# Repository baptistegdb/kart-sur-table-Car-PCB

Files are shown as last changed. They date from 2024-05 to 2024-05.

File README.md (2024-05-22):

# Projet de carte PCB pour le projet 'Kart Sur Table' 

## Description

Ce dépôt contient les fichiers de conception d'une carte PCB pour le projet 'Kart Sur Table'. La carte a été conçue pour remplacer le montage actuel utilisé cette année, qui est composé de nombreux modules assemblés les uns sur les autres. Le but de cette carte est de centraliser toutes les fonctionnalités nécessaires sur une même carte, afin d'optimiser l'espace disponible et de réduire la taille de l'électronique.
Fichiers

   - Rapport du projet.pdf : rapport de projet détaillant la conception de la carte PCB.
   - Peripherals.SchDoc : schématique des périphériques de la carte (IMU, pont en H pour les moteurs, boutons BOOT et EN, LED de contrôle).
   - power.SchDoc : schématique de l'alimentation de la carte (régulation de la tension en 5V et 3V3).
   - Controller.SchDoc : schématique du microcontrôleur de la carte (ESP32-WROOM-32E).
   - PCB1 25-03-2024 16-33-14.WAS : fichier de sauvegarde automatique de la conception de la carte PCB.
   - PCB1.cctpref : fichier de préférences de la conception de la carte PCB.
   - Schlib1.SchLib : bibliothèque de schémas pour la conception de la carte PCB.
   - PcbLib1.PcbLib : bibliothèque de PCB pour la conception de la carte PCB.
   - PCB1.PcbDoc : fichier de conception de la carte PCB.

## Conception de la carte PCB

La carte PCB a été conçue à l'aide du logiciel Altium Designer. Elle est composée de trois parties principales : les périphériques, l'alimentation et le microcontrôleur.
Périphériques

## Les périphériques de la carte sont les suivants :

   - Une IMU (LSM6DS3TR) pour mesurer l'accélération et la vitesse angulaire du kart.
   - Un pont en H (TB6612FNG) pour contrôler les deux moteurs du kart.
   - Deux boutons (BOOT et EN) pour démarrer et arrêter le microcontrôleur.
   - Deux LED (rouge et verte) pour indiquer l'état du microcontrôleur.

## Alimentation

L'alimentation de la carte est assurée par deux régulateurs de tension :

   - Un régulateur LDO (LMR14050) pour réguler la tension d'entrée (7,4V) à 5V.
   - Un régulateur LDO (TPS7A7002DDAR) pour réguler la tension de 5V à 3V3.

La carte est alimentée par une batterie LiPO de 7,4V/3600mAh, qui est connectée à la carte via un connecteur JST.
Microcontrôleur

Le microcontrôleur de la carte est un ESP32-WROOM-32E. Il est connecté aux périphériques et à l'alimentation de la carte via des connecteurs et des broches d'alimentation.

- pour en savoir plus consultez le Rapport du projet :

[Rapport du projet](https://github.com/baptistegdb/kart-sur-table-Car-PCB/blob/main/Rapport%20du%20projet.pdf)

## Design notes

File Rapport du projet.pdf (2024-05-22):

## Rapport du projet du cours d’électronique /

## carte PCB pour le projet ’Kart Sur Table’

Baptiste Gadebille

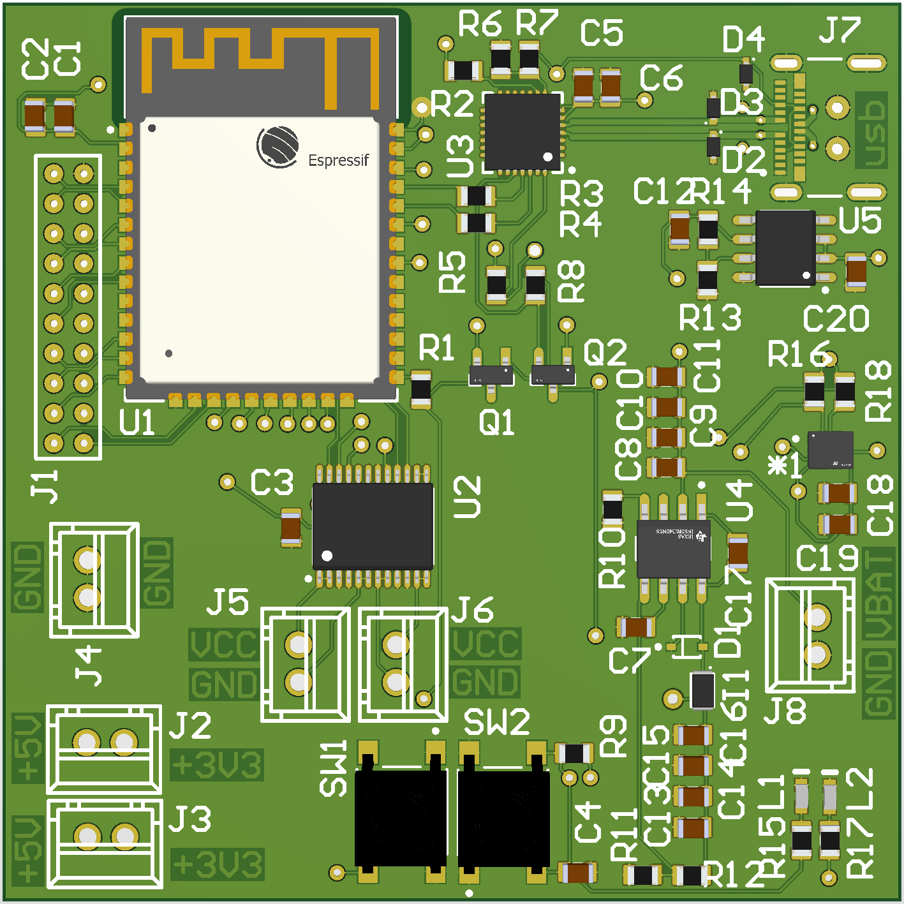
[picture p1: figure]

Figure 1: La Carte

1

Contents

1 Introduction | 5

1.5 Contrôle de trois moteurs à courant continu, avec seulement

2 Les Schématiques | 13
3 Gestion de l’alimentation | 14
4 Périphériques | 21

2

5 Microcontrôleur | 26
6 Composants | 33

3

7 Bilan énergétique | 37
8 Sources | 38

Figure 2: La Carte

4

### 1 Introduction

L’objectif du projet est de créer une carte électronique permettant de piloter à distance une voiture RC. Il est prévu qu’elle puisse fonctionner avec deux moteurs et utiliser une IMU. Son objectif est de devenir la première version d’une voiture RC pour le projet "Kart Sur Table", qui vise à concevoir et à mettre en œuvre un plateau intelligent et polyvalent en combinaison avec des voitures RC. L’objectif de cette carte est de poursuivre le projet de Yday "Kart Sur Table" qui vise à intégrer un plateau écran polyvalent et quatre petits robots capables de se déplacer sur ce plateau. Pour cette version, nous avons créé des petites voitures RC. Cette carte à été réalisé durant le module d’électronique, sur environ dix jours, du choix des composants, du calcule des régulateurs de tensions, à la réalisation de schématiques, en passant par la création de footprint, et jusqu’au routage de la carte.

Le but de cette carte est de remplacer le montage actuel utilisé cette année composé de nombreux modules assemblé les uns sur les autres. Par exemple, actuellement un simple module pont en H l298n prend la place d’un carré de 20mm sur 20mm alors que ce circuit intégré, en lui-même mesure moins d’un cinquième du module.

D’un point de vue unitaire, la taille excessive des modules et l’emplacement des supports semblent insignifiants pour un projet étudiant de petite envergure. Cependant, en prenant une perspective plus globale sur le projet et en considérant notre intention de le prolonger à une deuxième année afin de le terminer et de le rendre à l’état de prototype fonctionnel.

Dans ce but nous voulons faire fabriquer nos propres PCB dans le but d’optimisation les voitures RC, de faire baisser la taille de l’électronique, pour avoir les voitures les plus petites possible, avec le moins de supports internes. Tout cela provoque des contraintes de placement qui pourraient être évitées lors de la modélisation 3D.

5

### 1.1 Solution proposée

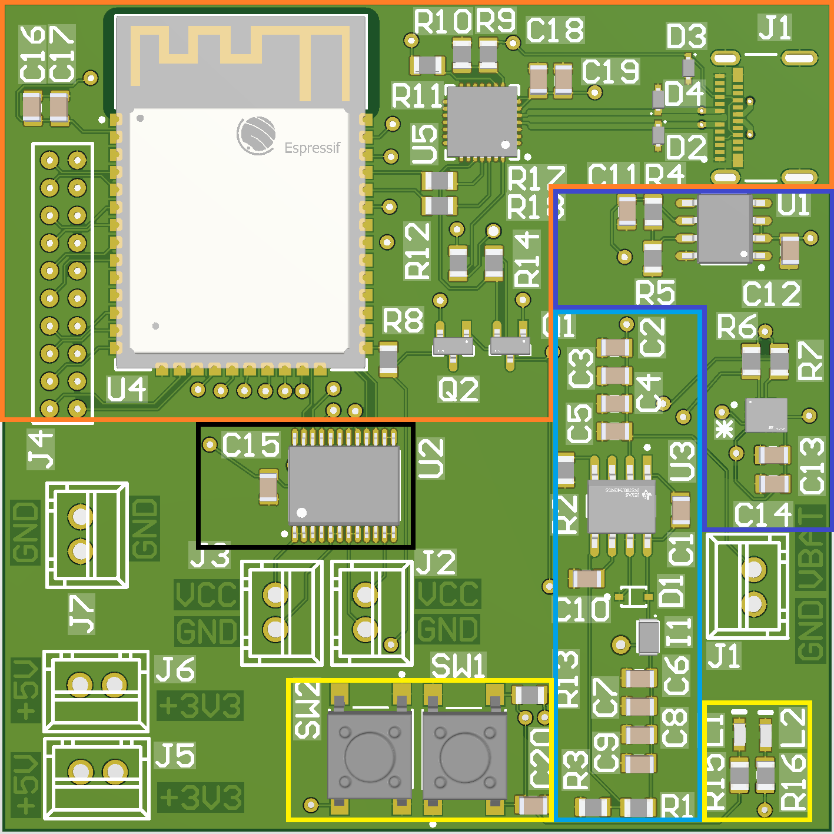
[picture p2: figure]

Figure 3: Une PCB pour remplacer toutes les autres.

La solution proposée est de tout centraliser sur une même carte :

- La carte est un carré de 50 mm par 50 mm
- La zone en orange correspond à la carte l’ESP32-WROOM-32E avec l’USB-C.
- La zone en bleu clair correspond à la partie régulation de la tension en 5v.
- La zone en bleu foncé correspond à la partie régulation de la tension en 3v3, cette zone contient aussi l’IMU juste au-dessus de C13.
- La zone noire correspond au pont en H pour les moteurs, vers les connecteurs J2 et J3.
- La zone jaune correspond aux boutons BOOT et EN ainsi qu’a des LED de contrôle.

6

- Le reste correspond aux connecteurs : J1 pour une batterie 5v, J2 et J3 pour les moteurs, J4 pour les 20 pins programmable de l’ESP, J5 et J6 pour des connecteurs 5v et 3v3 ainsi, de même, le connecteur J7 renvoi aux deux GND.

### 1.2 Dimensionnement des empreintes

Le dimensionnement des empreintes a été réalisé en fonction des spécifications des composants utilisés dans le projet.

Les empreintes des composants CMS sont au format 0805.

Et ont soit été réalisées à l’aide de l’outil IPC Footprint Wizard, soit elles proviennent directement de la bibliothèque Octopart.

### 1.3 Méthodologie du routage

La méthodologie de routage de la carte PCB a été réalisée en suivant les bonnes pratiques de conception. Les composants ont été placés de manière à optimiser l’espace disponible sur la carte bien qu’il y a eu de petites erreurs comme la position de certains condensateurs par exemple. Le routage a été effectué en commençant par les signaux critiques tels que les signaux différentiels, suivis des signaux signaux de données et enfin des d’alimentation. Les pistes ont été routés de manière à éviter les croisements et à minimiser les retours de masse.

Les paires différentielles de l’USB-C :

- Longueur de la piste USB_n : 22.954 mm
- Longueur de la piste USB_p : 23.159 mm

7

- La différence entre les deux longueurs est donc de 0.205mm
- Compte tenu de la tolérance spécifiée de 1 mm pour les paires différentielles USB-C, la différence de 0.205 mm est bien inférieure à cette tolérance. Par conséquent, les longueurs des pistes USB_n et USB_p respectent les spécifications de tolérance pour les paires différentielles USB-C.

– Le calcule de ces Paires différentielles a été fait grâce au logiciel "Saturn Pcb Toolkit" avec une résistance de 90 Ohms

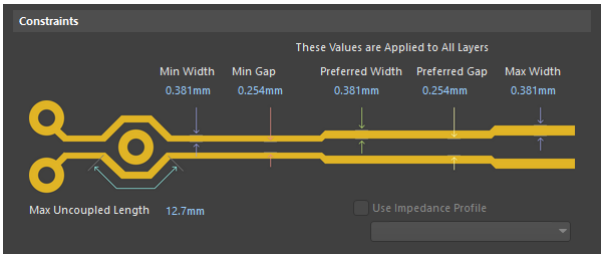
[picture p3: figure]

Figure 4:

8

### 1.4 Contraintes de routage et de fabrication

Lors du routage de la carte PCB, plusieurs contraintes ont été prises en compte pour assurer la fiabilité du circuit. Ces contraintes comprennent :

- Largeur et espacement des pistes : Les pistes ont été dimensionnées en fonction du courant qu’elles doivent supporter et de l’impédance requise. L’espacement entre les pistes a été choisi pour éviter les courtscircuits et les interférences électromagnétiques. Pour garantir une qualité de signal optimale, nous avons suivi les recommandations du fabricant concernant la largeur et l’espacement des pistes.
- Couches de la carte : La carte a été conçue avec quatre couches pour réduire la complexité du routage, améliorer la dissipation thermique et minimiser les interférences électromagnétiques. Ces couches sont les suivantes :

– Top Layer (couches externes)

∗ Signal

– Layer 1 (couche 1)

∗ Ground

– Layer 2 (couche 2)

∗ Power

– Bottom Layer (couches internes)

∗ Ground

La figure suivante illustre la répartition des couches de la carte.

9

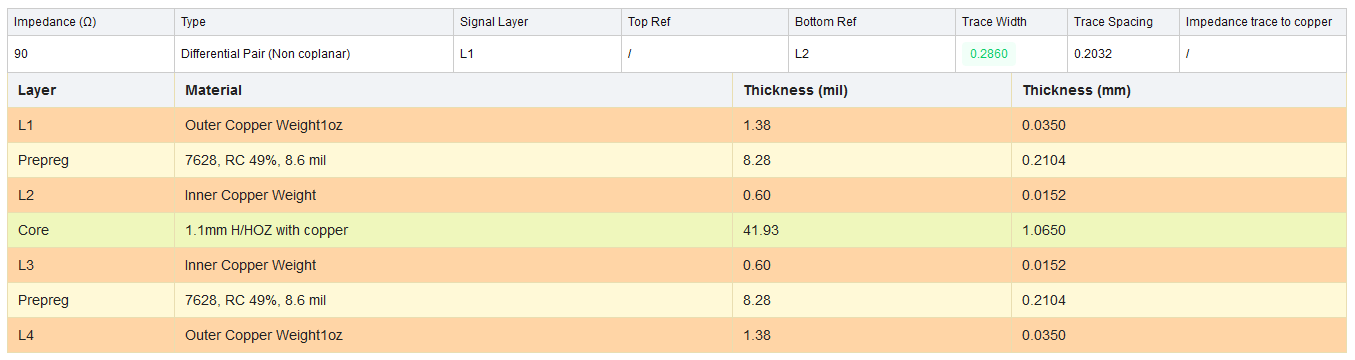
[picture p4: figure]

Figure 5: Tableau des couches de la carte

- Paires différentielles : Les paires différentielles ont été routées avec une différence de longueur de 0.205mm, ce qui est bien inférieure à la tolérance spécifiée de 1mm. Cette précision garantit que les longueurs des pistes USB_n et USB_p respectent les spécifications de tolérance pour les paires différentielles USB-C. Cela permet de minimiser les effets de diaphonie et d’assurer une transmission de signal fiable.
- Contraintes de fabrication : La carte a été conçue en tenant compte des contraintes de fabrication, telles que la taille minimale des vias, la taille des trous de montage et les tolérances de fabrication. Ces contraintes ont été vérifiées à l’aide des outils de contrôle de conception Design Rule Check (DRC). Les règles utilisées proviennent directement des règles de fabrication du site JLCPCB. Cette vérification garantit que la carte peut être fabriquée sans problème et fonctionnera correctement.

10

### 1.5 Contrôle de trois moteurs à courant continu, avec

seulement deux connectés à un pont en H

Le projet prévoit le contrôle de trois moteurs à courant continu, dont deux seront connectés à un pont en H pour permettre un contrôle bidirectionnel de la vitesse et de la direction. Le troisième moteur aura un contrôle unidirectionnel qui doit servir de bumper. Le moteur choisi est un mini moteur à engrenages 6V 50tr/min (12FN20).

### 1.6 Utilisation d’un micro-contrôleur de type ESP32

Le projet utilisera un micro-contrôleur ESP32 pour le traitement des données et le contrôle des composants. Ce micro-contrôleur a été choisi pour sa polyvalente, sa puissance de traitement qui correspond a nos besoins ainsi que sa connectivitée sans fil.

### 1.7 Commande des moteurs

La commande des moteurs sera assurée par le micro-contrôleur ESP32. Deux des moteurs seront connectés à un pont en H pour permettre un contrôle bidirectionnel de la vitesse et de la direction. Le troisième moteur aura un contrôle unidirectionnel, ce qui signifie qu’il ne pourra tourner que dans un sens.

### 1.8 Connectivité

Le projet utilisera une IMU (Unité de Mesure Inertielle) qui communique en I2C ou en SPI. Pour ce projet l’I2C à été choisi pour communique entre l’esp32 et l’IMU. L’IMU fournira des données sur l’orientation, la vitesse et

11 l’accélération de la voiture RC.

### 1.9 Contraintes supplémentaires

La conception de la carte doit tenir compte de la compacité et de la robustesse pour s’adapter à l’environnement de la voiture RC. Les composants doivent être sélectionnés pour leur faible consommation d’énergie afin de prolonger la durée de vie de la batterie. De plus, le système doit être conçu avec une certaine tolérance aux vibrations et aux chocs pour assurer un fonctionnement correct dans diverses conditions d’utilisation. Cela implique le choix de composants résistants et une conception mécanique adéquate.

12

### 2 Les Schématiques

La carte électronique en question se compose de trois parties principales de la carte électronique : Chaque partie est détaillée avec son fonctionnement et les composants utilisés.

la partie puissance, les périphériques et le micro-contrôleur.

La gestion de l’alimentation est un élément crucial dans tout système électronique, et cette section décrit comment la batterie LiPO de 7,4V/3600mAh est utilisée pour alimenter la carte électronique.

La section suivante décrit les périphériques tels que l’IMU, le pont en H et les connecteurs. Enfin, la section du micro-contrôleur décrit l’utilisation de l’ESP32-WROOM32E dans le projet de voiture RC.

Les choix des composants ont été guidés par plusieurs facteurs tels que la performance, la fiabilité, la consommation d’énergie et la compatibilité avec les autres composants du système.

Le choix des composants pour cette carte électronique a été guidé par plusieurs facteurs, notamment la performance, la fiabilité, la consommation d’énergie et la compatibilité avec les autres composants du système.

13

### 3 Gestion de l’alimentation

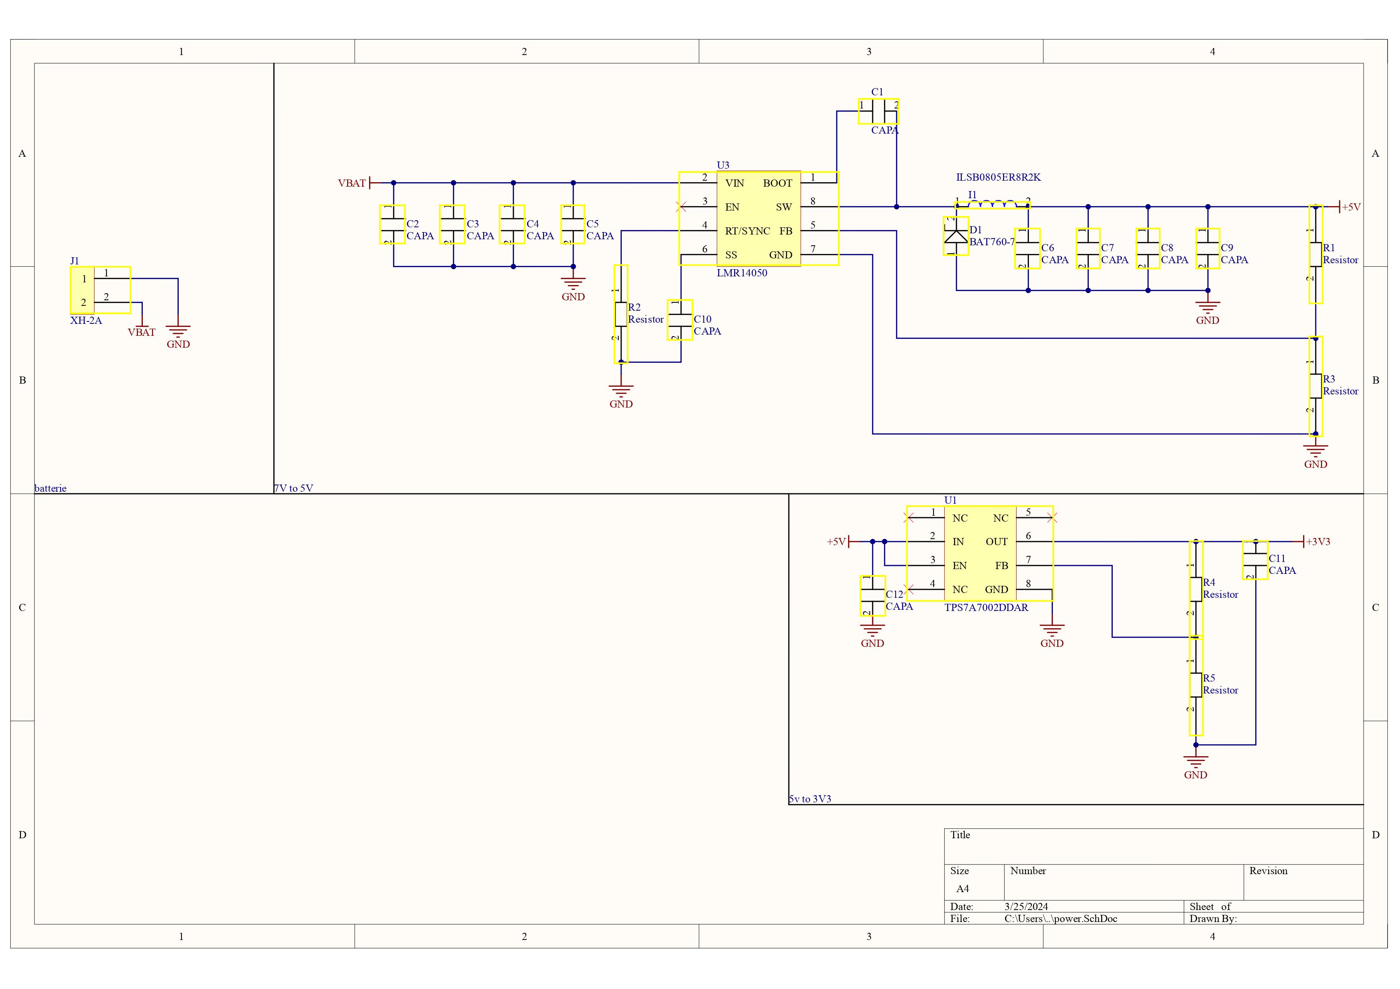
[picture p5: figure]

Figure 6: Enter Caption

La gestion de l’alimentation est un élément crucial dans tout système électronique. Elle permet de fournir l’énergie nécessaire au fonctionnement de tous les composants. Dans notre projet de voiture RC, nous avons utilisé une batterie LiPO de 7,4V/3600mAh pour alimenter la carte électronique qui convertie la tension vers 5v, et enfin à du 3v3 vers le micro-contrôleur .

La section de gestion de l’alimentation de la carte électronique se compose d’un connecteur pour la batterie, d’un régulateur de tension LDO LMR14050 pour fournir une tension de 5V, et d’un régulateur de tension LDO TPS7A7002DDAR pour fournir une tension de 3,3V.

Le connecteur pour la batterie doit être compatible avec la batterie spécifique

14 utilisée dans le projet. Dans ce cas, le connecteur doit correspondre aux spécifications de la batterie LiPO 7,4V/3600mAh 60C. La batterie choisie pour ce projet a une capacité de 3600 mAh et une tension nominale de 7,4
V. Cela signifie qu’elle peut fournir une quantité d’énergie maximale de 26,64 Wh (watt-heures). La capacité élevée de cette batterie permet une durée de fonctionnement prolongée de la voiture RC.

15

### 3.0.1 LDO LMR14050

Le montage proposé pour le régulateur à découpage LMR14050 a été vérifié et validé en se basant sur les calculs et recommandations fournis dans la datasheet du composant.

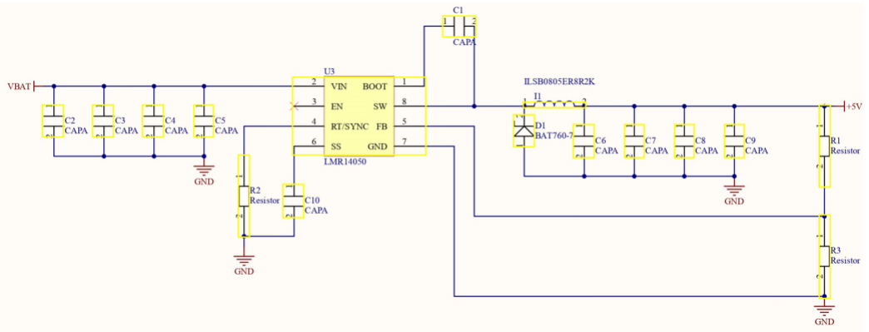
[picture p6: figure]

Figure 7: ldo 7v to 5v

- Condensateurs d’entrée : Quatre condensateurs ont été placés entre l’entrée VIN et la masse, avec des valeurs respectives de 47 µF, 22 µF, 22 µF et 100 µF. Cette combinaison de condensateurs assure un découplage efficace de l’alimentation d’entrée et réduit les ondulations.
- Résistance RT/SYNC : Une résistance de 84,5 k Ohms a été placée sur le pin RT/SYNC et reliée à la masse. Cette résistance détermine la fréquence de découpage du régulateur. Selon la datasheet, la fréquence de découpage (fSW) peut être calculée à l’aide de l’équation suivante :
- Selon la datasheet, la fréquence de découpage (fSW) peut être calculée à l’aide de l’équation suivante :

fSW = 1/(2.4 ∗ RT)

Avec RT = 84,5 k Ohms, la fréquence de découpage est :

fSW = 1/(2.4 ∗ 84.5kOhms) = 300kHz

16

Cette valeur correspond à la fréquence de découpage souhaitée pour le montage.

- Condensateur de soft-start : Un condensateur de 20 nF a été placé sur la pin SS et relié à la masse. Ce condensateur est utilisé pour contrôler le temps de démarrage progressif du régulateur.
- Selon la datasheet, le temps de démarrage progressif (tSS) peut être calculé à l’aide de l’équation suivante :

tSS = CSS ∗ (V IN/ISS)

où CSS est la valeur du condensateur de soft-start, VIN est la tension d’entrée, et ISS est le courant de charge du condensateur de soft-start (3 µA). Avec CSS = 20 nF, VIN = 7,4 V, et ISS = 3 µA, le temps de démarrage progressif est :

tSS = 20nF ∗ (7, 4V/3A) = 5ms

Cette valeur correspond au temps de démarrage progressif souhaité pour le montage.

- Condensateur de bootstrap : Un condensateur de 100 nF a été placé entre le pin BOOT et le pin SW. Ce condensateur est utilisé pour fournir une tension de polarisation au circuit de commande du MOSFET interne. La datasheet recommande d’utiliser un condensateur de 100 nF pour cette application.
- Diode, inductance et condensateurs de sortie : Une diode, une bobine de 8,2 µH et quatre condensateurs de 47 µF ont été placés entre le pin SW et le rail de sortie de 5 V. Ces composants forment le circuit de sortie du régulateur. La datasheet recommandé d’utiliser une inductance comprise entre 4,7 µH et 22 µH pour une application de 5 V/5 A.

17

Le choix d’une inductance de 8,2 µH est légèrement supérieur à cette recommandation, mais reste adapté au montage. Les condensateurs de sortie assurent une bonne découplage de la tension de sortie et réduisent les ondulations.

- Pont diviseur de tension : Un pont diviseur de tension a été mis en place entre le rail de sortie de 5 V et le pin FB, composé des résistances R1 de 100 k Ohms et R3 de 17,8 k Ohms. Ce pont diviseur de tension est utilisé pour réguler la tension de sortie du régulateur. Selon la datasheet,
- Selon la datasheet, la tension de sortie (VOUT) peut être calculée à l’aide de l’équation suivante :

V OUT = V F B ∗ (1 + R1/R3)

où VFB est la tension de référence interne du régulateur (0,75 V). Avec R1 = 100 k Ohms et R3 = 17,8 k Ohms, la tension de sortie est :

V OUT = 0, 75V ∗ (1 + 100kOhms/17, 8kOhms) = 5V

18

### 3.0.2 LDO TPS7A7002DDAR

- Le régulateur LDO TPS7A7002 est utilisé dans le montage pour réguler la tension d’entrée de 5V à une tension de sortie de 3,3V. Pour ce faire, un pont diviseur de tension est utilisé pour fournir une tension de référence à la broche FB du régulateur.

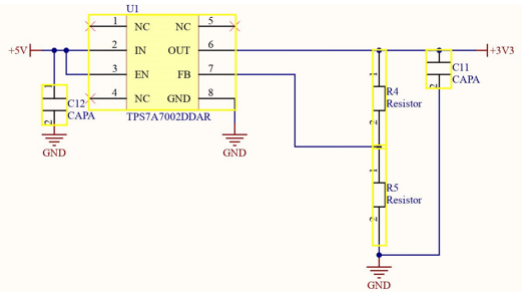
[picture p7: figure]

Figure 8: LDO 5v to 3v3

- La valeur de la tension de référence est déterminée par les résistances R1 et R2 du pont diviseur de tension.
- La formule pour calculer la tension de sortie (Vout) du régulateur est la suivante :

V out = V ref ∗ (1 + R1/R2)

- Où Vref est la tension de référence (dans ce cas, la tension à la broche FB) et R1 et R2 sont les résistances du pont diviseur de tension.

19

- Dans le montage, R1 = 169 k Ohms et R2 = 30,1 k Ohms. En utilisant ces valeurs et en sachant que la tension de sortie souhaitée est de 3,3 V, nous pouvons résoudre l’équation pour trouver la tension de référence nécessaire à la broche FB :

3, 3V = V ref ∗ (1 + 169kOhms/30, 1kOhms)

V ref = 3, 3V/(1 + 169kOhms/30, 1kOhms) = 0, 5V

- Par conséquent, la tension de référence à la broche FB doit être de 0,5 V pour obtenir une tension de sortie de 3,3 V.
- Le condensateur de 100 nF entre la broche IN et la broche EN est utilisé pour réduire le bruit et améliorer la stabilité du régulateur. Le condensateur de 100 nF entre le nœud du pont diviseur de tension et la sortie de 3,3 V est également utilisé pour réduire le bruit et améliorer la stabilité du régulateur.

20

### 4 Périphériques

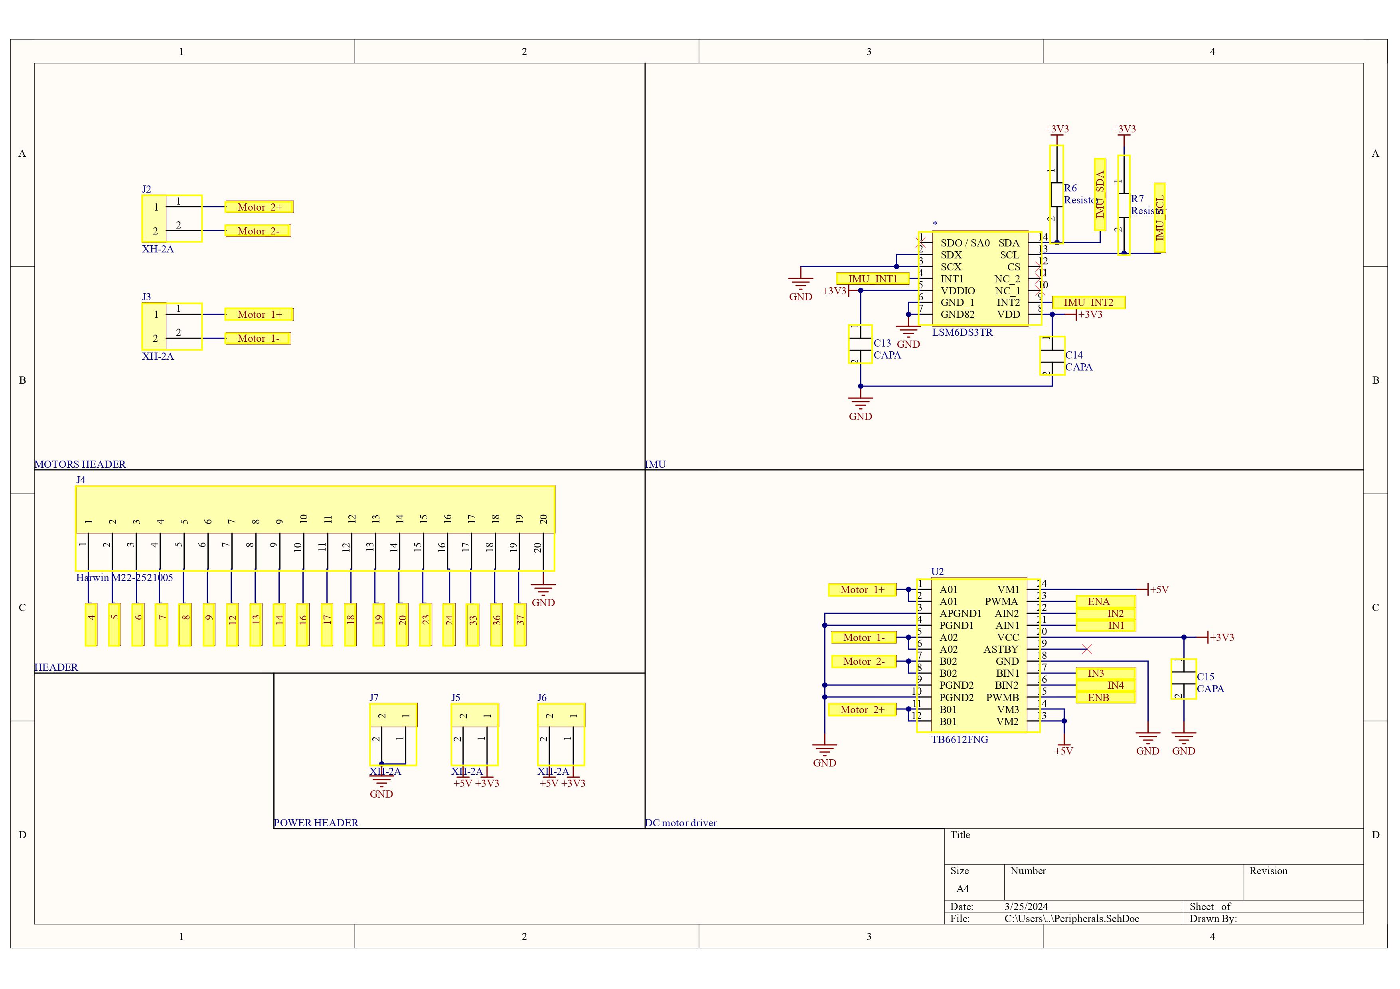
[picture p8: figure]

Figure 9: Les Périphériques

La carte électronique est équipée de plusieurs périphériques clés, notamment une unité de mesure inertielle (IMU), un pont en H, des connecteurs pour les moteurs et des connecteurs d’alimentation. L’IMU est utilisée pour mesurer l’accélération, la vitesse angulaire et l’orientation du robot, tandis que le pont en H est utilisé pour contrôler les moteurs du robot. Les connecteurs d’alimentation fournissent l’énergie nécessaire au fonctionnement de la carte électronique et des périphériques associés.

21

### 4.1 Le Pont en H

Le pont en H est utilisé pour contrôler les moteurs. Dans ce cas, le condensateur C15 est utilisé comme filtre low pass. Le TB6612FNG fourni un courant

de sortie importante et offre une faible résistance à l’état ON, ce qui améliore l’efficacité énergétique. De plus, il offre, des protections intégrées, et à un boîtier compact, parfait pour des contraintes de places. Ces caractéristiques

en font un pont en H équilibré et performant. De plus il permet de piloter deux moteurs indépendamment l’un de l’autre. Avec un courant de sortie maximum de 3,2 A pour les deux sorties, et une protection thermique.

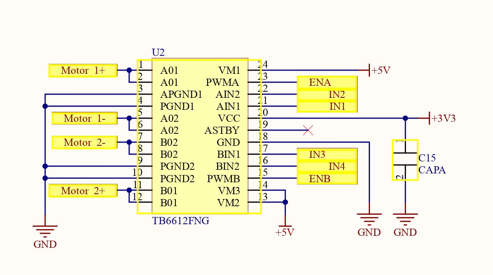
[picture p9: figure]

Figure 10: Le pont en H

22

### 4.2 l’IMU (LSM6DS3TR)

Le design utilisé pour l’IMU LSM6DS3TR reprend celui de la documentation technique du composant. Dans ce cas d’utilisation, les condensateurs C13 et C14 servent de filtres low pass, tandis que les résistances R6 et R7 servent de filtres high pass.

Ce circuit imprimé intègre un accéléromètre 3 axes, un gyroscope 3 axes et un magnétomètre 3 axes, le LSM6DS3TR servira a terme pour une implementation de l’odométrie.

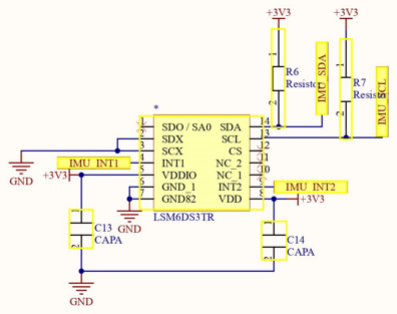
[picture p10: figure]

Figure 11: L’IMU

23

### 4.3 Les connecteurs

Le connecteur XH-2A est un choix pratique et efficace pour les applications nécessitant une connexion fil à carte.

Ce connecteur à insertion est facile d’utilisation, de plus, ce connecteur est durable.

Avec un pas de 2,5 mm, le connecteur XH-2A est relativement petit, ce qui le rend idéal pour les applications où l’espace est limité.

Les headers XH-2A sont utilisés pour alimenter des modules externes comme les moteus DC, ou autres, via les broches GND, 3V3, 5V.

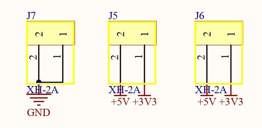
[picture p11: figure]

Figure 12: Connecteurs +5V, +3V3, GND

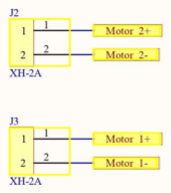
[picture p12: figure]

Figure 13: Deux connecteurs pour les moteurs

Les connecteurs moteurs relient directement les moteurs au pont en H.

24

L’autre connecteur est utilisés pour pouvoir ajouter si besoin des capteurs et des actionneurs. Ils permettent également d’améliorer le système.

Ce connecteur aux nombreux pins est en deux fois dix broches, cela permet de concentrer les broches au même endroit plutôt que de n’avoir pas plusieurs connecteurs routés au microcontrôleur.

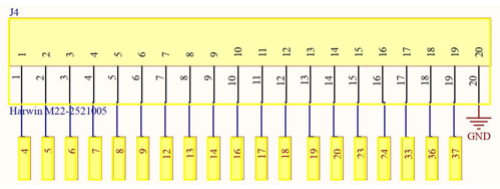
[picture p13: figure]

Figure 14: Connecteurs esp32

25

### 5 Microcontrôleur

Le microcontrôleur utilisé dans cette carte électronique est l’ESP32-WROOM32E.

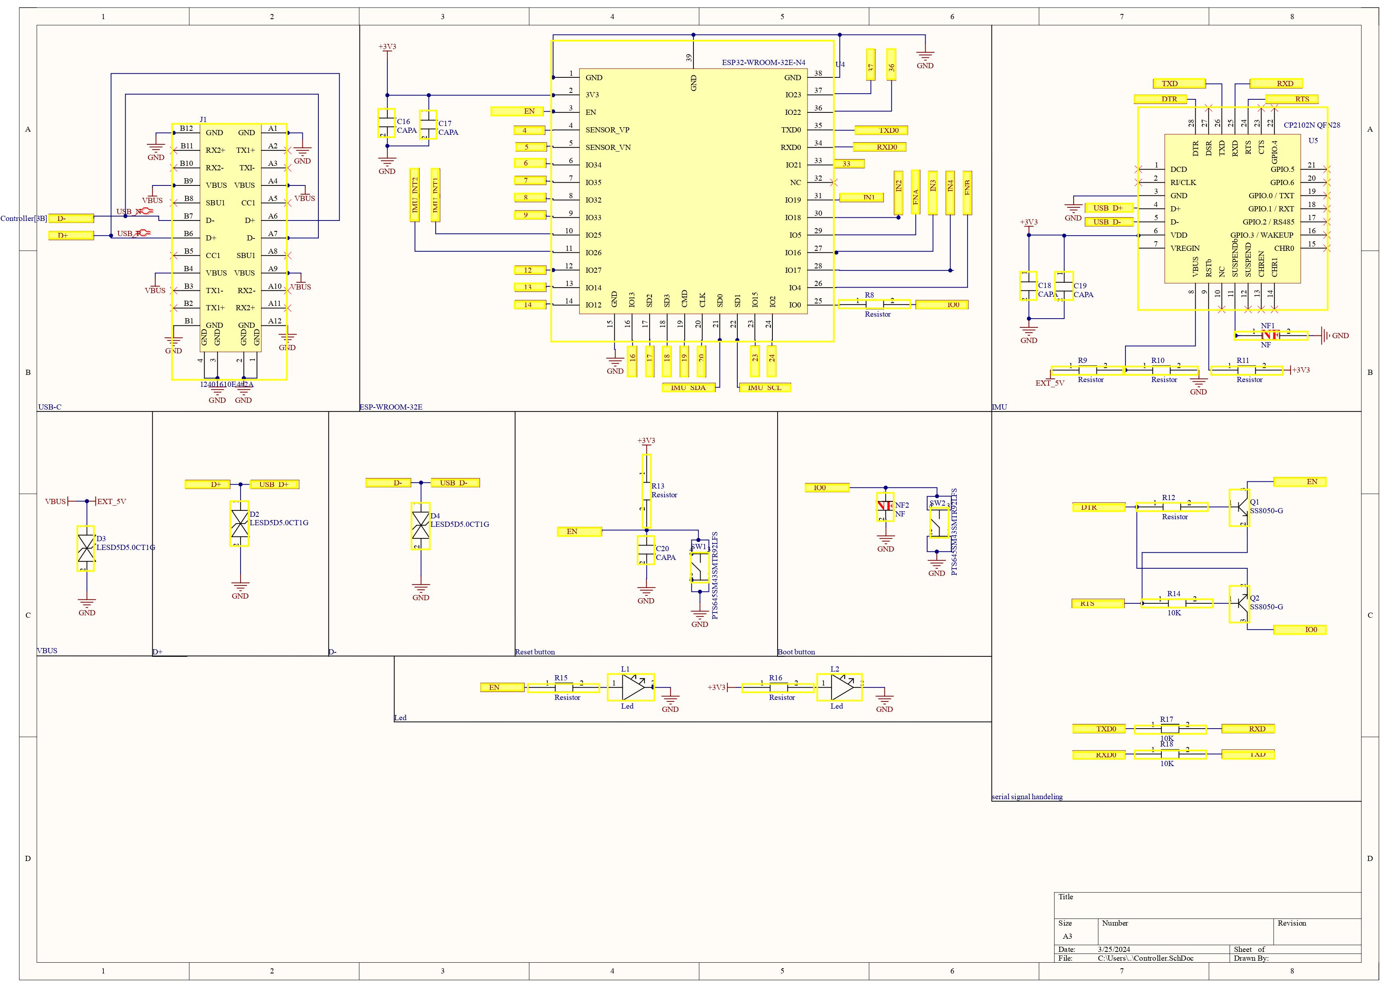
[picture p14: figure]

Figure 15: Enter Caption

L’ESP32-WROOM32E est un microcontrôleur populaire utilisé dans de nombreuses applications IoT. Dans notre projet de voiture RC, nous avons connecté les différentes broches de l’ESP32 aux headers correspondants sur la carte électronique.

Le microcontrôleur a une faible consommation d’énergie, ce qui permet une durée de fonctionnement prolongée de la voiture RC lorsque le microcontrôleur n’est pas en fonctionnement actif.

26

Nous avons également utilisé des boutons Reset et Boot pour réinitialiser le microcontrôleur et passer en mode de téléchargement de programme, ainsi qu’un pont USB pour convertir les signaux USB en signaux série et connecter la carte électronique à un ordinateur ou à un autre périphérique USB.

Le connecteur USB est utilisé pour charger le programme dans le microcontrôleur et communiquer avec la carte électronique.

La carte possède des LED de vérifications, ces leds sont utilisées pour vérifier si le ’3v3’ et le ’EN’ fonctionnent correctement. Elles servent de vérification pour s’assurer que la carte électronique est correctement alimentée.

Figure 16: Led de vérifications

27

### 5.1 ESP32-WROOM32E

L’ESP32-WROOM32E est un microcontrôleur populaire utilisé dans de nombreuses applications IoT, le modèle L’ESP32-WROOM32E à l’avantage d’avoir une antenne intégré.

Dans ce cas, les condensateurs C16 et C17 servent de filtres low pass. Les différents pins présents sur l’esp sont connecté aux headers.

Le microcontrôleur ESP32-WROOM-32E a une consommation d’énergie de 180 mA en mode actif et de 10 µA en mode veille profonde.

Cette faible consommation d’énergie en mode veille profonde permet une durée de fonctionnement prolongée de la voiture RC lorsque le microcontrôleur n’est pas en fonctionnement actif.

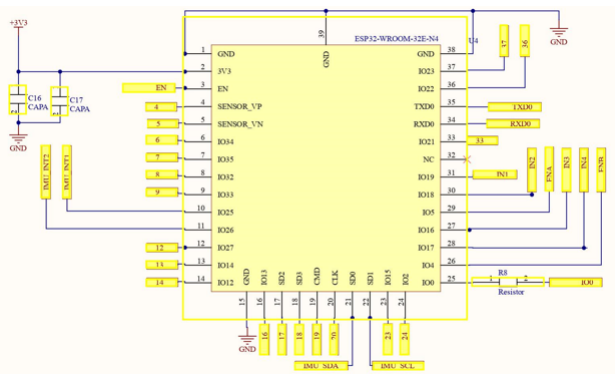
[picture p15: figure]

Figure 17: ESP-WROOM-32E

28

### 5.2 Broches ENABLE/IO0 et boutons Reset et Boot

Les boutons Reset et Boot sont utilisés pour réinitialiser le microcontrôleur et pour passer en mode de téléchargement de programme. Pour le bouton reset, un nœud composé du bouton poussoire et d’un filtre low pass, ainsi que d’un filtre high pass est utilisé en amont de la pin EN.

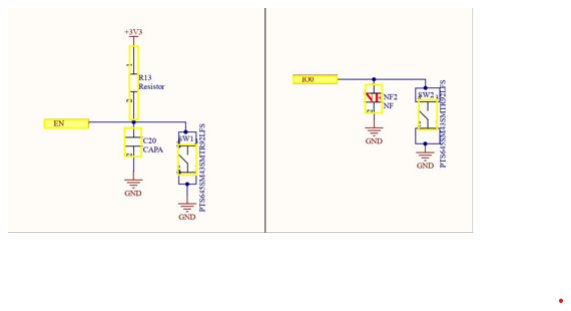
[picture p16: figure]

Figure 18: Boutons Reset et Boot

La séquence automatique des broches ENABLE/IO0 est utilisée pour le téléchargement du programme sur l’ESP32-WROOM32E. Le design de cette partie provient du pont USB. Les transistors utilisés dans ce schéma sont de type NPN.

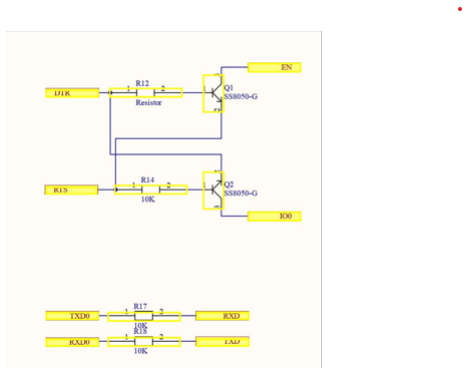
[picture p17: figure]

Figure 19: UART & ×EN+IO0

29

### 5.3 le bridge USB

Le pont USB est utilisé pour convertir le signal des paires différentielles USB-D+ et USB-D- vers de l’uart RX TX.

Dans ce cas, les condensateurs C18 et C19 servent de filtres low pass, tandis que les résistances R9 et R10 servent de pont diviseur de tensions pour le pin RSTb.

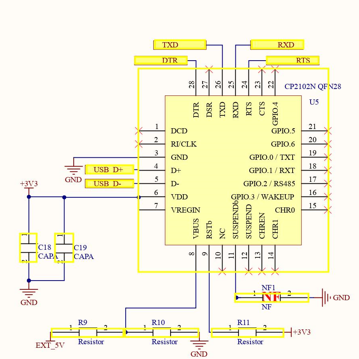
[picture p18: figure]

Figure 20: Pont USB

Les diodes de protection utilisées ici servent à protéger la carte électronique contre les surtensions elles se situent entre le connecteur USB-C et le pont USB, et supportent une tension de 550 mV à 30 V et un courant de 1 A. Au

niveau des pistes USB_N USB_P et EXT_5V.

30

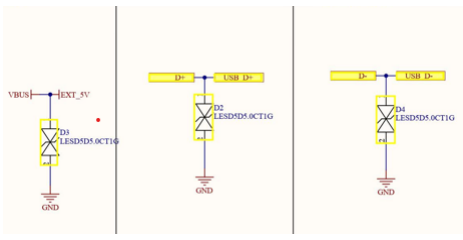
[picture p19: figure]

Figure 21: Diode de sécuritée

Le design de cette partie provient également du designe de l’ESP32_WROOM_32E.

31

### 5.3.1 Connecteur USB

Le connecteur USB est utilisé pour connecter la carte électronique à un ordinateur ou à un autre périphérique USB.

Le pont USB est un circuit électronique qui permet de convertir des signaux USB en signaux série. Il est utilisé pour connecter des périphériques USB

à des microcontrôleurs qui n’ont pas de port USB intégré. Dans notre cas, nous avons un pont USB CP2102N QFN28 (U5) qui supporte un courant de 200 mA. dans le designe classique de la carte esp32_wroom32E le port est

un micro-USB.

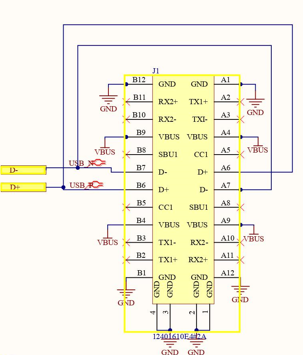
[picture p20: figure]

Figure 22: Schéma du connecteur USB

Ce connecteur est utilisé pour connecter la carte électronique à un ordinateur ou à un autre périphérique USB. Il permet de charger le programme dans le microcontrôleur et de communiquer avec la carte électronique.

32

### 6 Composants

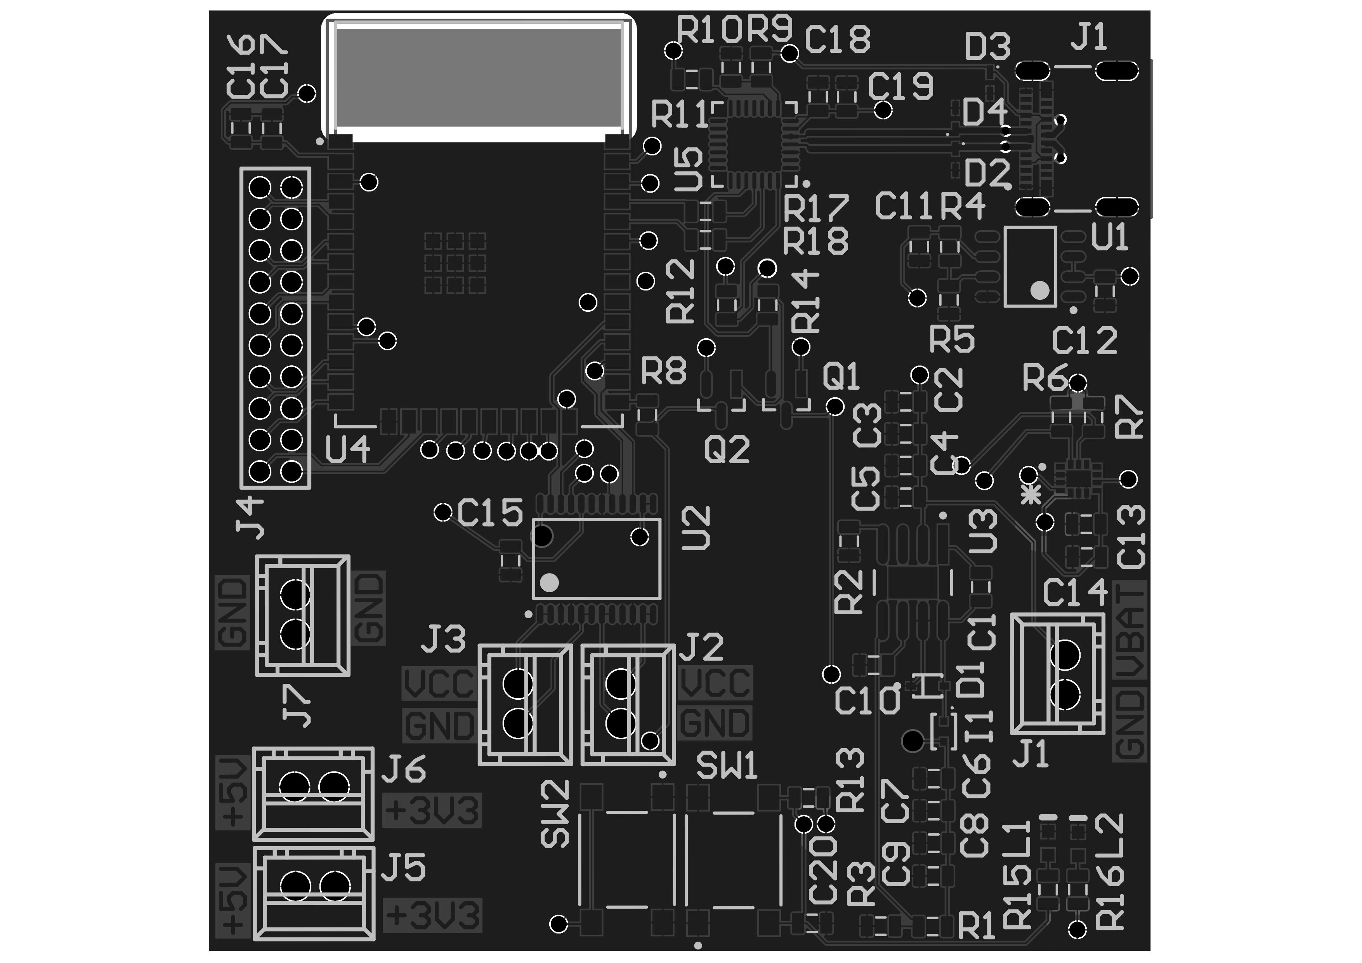
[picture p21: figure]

Figure 23: Image de la Carte

La section "Composants" de ce document fournit une liste détaillée de tous les composants utilisés dans la carte électronique. Cette section comprend des

sous-sections pour chaque type de composant, y compris les condensateurs, les résistances, les connecteurs, les ponts USB, les transistors, les diodes, les boutons-poussoirs, les régulateurs de tension (LDO), les ponts en H, les microcontrôleurs, les IMU et les inductances.

33

### 6.1 Condensateurs

Référence & Quantité
100nF & ×8 (C1, C5, C11, C12, C13, C14, C15, C19) 47uF & ×5 (C2, C6, C7, C8, C9)
2.2uF & ×2 (C3, C4)
20nF & ×1 (C10)
22uF & ×1 (C16)
0.1uF & ×1 (C17)
4.7uF & ×1 (C18)
1uF & ×1 (C20)

### 6.2 Résistances

Référence & Quantité
100K & ×1 (R1)
84K5 & ×1 (R2)
17K8 & ×1 (R3)
169K & ×1 (R4)
30K1 & ×1 (R5)
4.7K & ×2 (R6, R7)
22Ohm & ×1 (R8)
22K & ×1 (R9)
47K & ×1 (R10)
1K & ×1 (R11)
10K & ×7 (R12, R13, R14, R15, R16, R17, R18)

34

### 6.3 Connecteurs

Référence & Quantité
XH-2A & ×6 (J2, J3, J5, J6, J7, J8) Harwin M22-2521005 & ×1 (J4) LED & ×2 (L1, L2)
12401610E4#2A & ×1 (J1)

### 6.4 Pont USB

Référence & Quantité
CP2102N QFN28 & ×1 (U5 - 200 mA)

### 6.5 Transistors

Référence & Quantité
SS8050-G & ×2 (Q1, Q2)

### 6.6 Diodes

Référence & Quantité
BAT760-7 & ×1 (D1 - Supporte 550 mV - 30 V, 1 A) LESD5D5.0CT1G & ×3 (D2, D3, D4)

35

### 6.7 Boutons-poussoirs

Référence & Quantité
PTS645SM43SMTR92LFS & ×2 (SW1, SW2)

### 6.8 Régulateurs de tension (LDO)

Référence & Quantité
TPS7A7002DDAR & ×1 (U1 - 3 mA) LMR14050 & ×1 (U3 - 40 uA)

### 6.9 Pont en H

Référence & Quantité
TB6612FNG & ×1 (U2 - 1.2 A)

### 6.10 Microcontrôleur

Référence & Quantité
ESP32-WROOM-32E-N4 & ×1 (U4 - 3.0 3.6 V, 0.5 A)

### 6.11 IMU

Référence & Quantité
LSM6DS3TR & ×1 (Consommation maximale : 0.90 mA)

36

### 6.12 Inductance

Référence & Quantité
ILSB0805ER8R2K & ×1 (I1 - 8.2uH)

### 7 Bilan énergétique

La section "Bilan énergétique" fournit une estimation du courant total consommé par la carte électronique. Cette estimation est calculée en additionnant le courant consommé par chaque composant de la carte. Le courant total est calculé comme suit :

Le courant total (I_total) est calculé comme suit :

I_total = I_U1 + I_U2 + I_U3 + I_U4 + I_U5

I_total = 0, 003A + 1, 2A + 0, 00004A + 0, 5A + 0, 2A

I_total = 1, 90304A(environ).

37

### 8 Sources

Enfin, la section "Sources" fournit une liste de toutes les références utilisées dans ce document. Cette liste comprend des liens vers les fiches techniques et les schémas des composants utilisés dans la carte électronique.

References

[1] ESP-WROVER-KIT V4.1, Schematic, Espressif Systems, 2020.

Disponible en ligne : https://dl.espressif.com/dl/schematics/

ESP-WROVER-KIT_V4_1.pdf. (https://dl.espressif.com/dl/schematics/ESP-WROVER-KIT_V4_1.pdf)

[2] NodeMCU-32S, Schematic, 2019. Disponible en ligne : https:

//i0.wp.com/circuitsetup.us/wp-content/uploads/2019/09/

nodemcu_32s_sch.png?fit=1327%2C879&ssl=1. (https://i0.wp.com/circuitsetup.us/wp-content/uploads/2019/09/nodemcu_32s_sch.png?fit=1327%2C879&ssl=1)

[3] ESP32-WROOM-32E, Datasheet, Espressif Systems, 2019. Disponible

en ligne : https://www.espressif.com/sites/default/files/

documentation/esp32-wroom-32e_esp32-wroom-32ue_datasheet_

en.pdf. (https://www.espressif.com/sites/default/files/documentation/esp32-wroom-32e_esp32-wroom-32ue_datasheet_en.pdf)

[4] BAT760-7, | Diode, | Diodes | Incorporated, | 2017. | Disponible
en | ligne | : | https://www.digikey.com/en/products/detail/

diodes-incorporated/BAT760-7/697106. (https://www.digikey.com/en/products/detail/diodes-incorporated/BAT760-7/697106)

[5] LESD5D5.0CT1G, Diode, Lite-On Semiconductor, 2019. Disponible

en ligne : https://www.lcsc.com/datasheet/lcsc_datasheet_

1912111437_LRC-LESD5D5-0CT1G_C383211.pdf. (https://www.lcsc.com/datasheet/lcsc_datasheet_1912111437_LRC-LESD5D5-0CT1G_C383211.pdf)

[6] "12401610E4#2A", USB Type-C Connector, Amphenol Commercial Products, 2018. Disponible en ligne : https://cdn.amphenol-cs.com/

38 (https://cdn.amphenol-cs.com/media/wysiwyg/files/documentation/datasheet/inputoutput/io_usb_type_c.pdf)

media/wysiwyg/files/documentation/datasheet/inputoutput/io_

usb_type_c.pdf. (https://cdn.amphenol-cs.com/media/wysiwyg/files/documentation/datasheet/inputoutput/io_usb_type_c.pdf)

[7] SS8050-G, N-Channel Enhancement Mode Field Effect Transistor, Diodes Incorporated, 2018. Disponible en ligne : https://www.mouser.

fr/datasheet/2/80/SS8050_G_RevA181526-2506539.pdf. (https://www.mouser.fr/datasheet/2/80/SS8050_G_RevA181526-2506539.pdf)

[8] PTS645SM43SMTR92LFS, Tactile Switch, C&K Switches, 2018.

Disponible en ligne : https://www.ckswitches.com/media/1471/

pts645.pdf. (https://www.ckswitches.com/media/1471/pts645.pdf)

[9] TPS7A7002DDAR, Linear Regulator, Texas Instruments, 2019.

Disponible en ligne : https://www.ti.com/lit/ds/symlink/

tps7a7002.pdf. (https://www.ti.com/lit/ds/symlink/tps7a7002.pdf)

[10] LMR14050, Linear Regulator, Texas Instruments, 2018. Disponible en

ligne : https://www.ti.com/lit/ds/symlink/lmr14050.pdf.

[11] TB6612FNG, H-Bridge Motor Driver, Toshiba, 2014. Disponible en

ligne : https://toshiba.semicon-storage.com/info/TB6612FNG_

datasheet_en_20141001.pdf?did=10660&prodName=TB6612FNG. (https://toshiba.semicon-storage.com/info/TB6612FNG_datasheet_en_20141001.pdf?did=10660&prodName=TB6612FNG)

[12] CP2102N QFN28, USB to UART Bridge Controller, Silicon Labs, 2019.

Disponible en ligne : https://www.silabs.com/documents/public/

data-sheets/cp2102n-datasheet.pdf. (https://www.silabs.com/documents/public/data-sheets/cp2102n-datasheet.pdf)

39
